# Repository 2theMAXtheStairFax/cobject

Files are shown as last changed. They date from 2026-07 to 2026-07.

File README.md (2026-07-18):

# Sky Cob — Weather Balloon Payload

Sky Cob is UWOSLAB's recoverable, high-altitude weather balloon payload. It's built around a SpeedyBee F405 Wing flight controller running INAV, packaged inside a 3D-printed shell, and monitored over an ELRS RC link. This repo holds everything needed to reproduce the payload build: the flight controller configuration, the radio (transmitter) model, and the 3D-printable enclosure.

> [!CAUTION]
> Please read this description in full before starting!

## Repository contents

| File | What it is |
|---|---|
| `INAV_9.0.1_cli_SKY_COB_20260701_003845.txt` | INAV 9.0.1 CLI dump for the flight controller (target `SPEEDYBEEF405WING`). Paste/load this into the INAV Configurator CLI tab to reproduce the full flight controller setup. |
| `Sky Cob.yml` | EdgeTX radio model ("Sky Cob") for the transmitter — ELRS module setup plus telemetry screens (RSSI, GPS, altitude, battery, attitude, flight mode). |
| `cobshell.stl` | Main payload shell in upright position. |
| `cobby20x40.stl` | Receiver and VTX Mounting plate |
| `cobbyspeedy-top.stl` | Top mounting plate sized for the SpeedyBee F405 Wing FC. |
| `cobby19mm_cam_stand.stl` | Main Chassis for components. |
| `fix model.stl` | Current Shell model in printing orientation for 250x250 bed. |

## Related projects

- [sky-cob-configurator](https://github.com/2theMAXtheStairFax/sky-cob-configurator) — a simplified, balloon-only fork of INAV Configurator. Strips out everything irrelevant to a servo-only, non-autonomous balloon payload (motor mixer, RTH, failsafe, etc.) and adds a one-click "Apply Balloon Defaults & Reboot" button to set up a fresh flight controller. Verified against real Sky Cob hardware. See [docs/weather-balloon-configurator.md](docs/weather-balloon-configurator.md) for the design and status.

## Hardware you'll need

- SpeedyBee F405 Wing flight controller (INAV target `SPEEDYBEEF405WING`)
- GPS module (uBlox; config uses SBAS/WAAS + Galileo + BeiDou + GLONASS) Preferred: HGLRC M100 Pro or Foxeer M10
- ExpressLRS receiver, Radiomaster DBR4 preferred.
- High power VTX. Read your VTXs manual for Band, Channel, Power, and Unlocking procedures.
- microSD card, for blackbox logging. Maximum 4GB usable, any extra space will not be utilized.
- 3D printer capable of printing the shell/mount parts above
- An EdgeTX compatible transmitter with an ELRS module, for `Sky Cob.yml`. Preferred Module for ground station telemetry tracking: Radiomaster Nomad on a Radiomaster Boxer

## Setup

### 1. Print the payload shell and assemble

Print `cobby20x40.stl`, `cobbyspeedy-top.stl`, `cobby19mm_cam_stand.stl`, and `fix model.stl`. Test-fit the FC mount (`cobbyspeedy-top.stl`) against your actual SpeedyBee F405 Wing board before committing to a full print run, since mounting hole tolerances are easy to get slightly wrong between printers/materials.

> [!WARNING]
> Models and files are still WIP. Please check for any recent updates before starting.

1. Place the flight controller in its bay. Make sure the orientation is correct when inserting. Place the FC cover on top and screw down with M2.5 bolts. Self tapping and machine screws will both work, as long as the FC is firmly mounted without wiggling.
2. Mount the GPS on the top platform with double sided VHB tape or glue, direction does not matter as we will not be using its built in compass (if your GPS unit has one).
3. Place the RX and VTX on the 20x20mm holes in the X shaped mounting plate. Bolt through the receiver and into the VTX using M2 bolts. Place the subassembly on the rear 40x40mm standoffs and bolt it down with the RX facing inwards and the VTX outwards.
4. Use double sided VHB tape, glue, or battery straps to mount your 5G GPS tracker to the rear side of the chassis, between the 2 large holes towards the bottom. Do the same with your 12V/3S battery on the other side.
5. Mount your analog camera to the 19mm wide bracket at the bottom. It should be pointing staight down.

### 2. Flash and configure the flight controller (INAV 9.0.1)

1. Install the [INAV Configurator](https://github.com/iNavFlight/inav-configurator) Git release 9.0.2.
2. Flash the `SPEEDYBEEF405WING` target to the board. use INAV 9.0.1 when flashing.
> [!IMPORTANT]
> - Install ImpulseRC Driver Fixer if you have not already, this will let you install the DFU BOOTLOADER Drivers.
> - If target is not found automatically, check if a new COM port has been listed in the top right dropdown and select it before switching to the Firmware Flasher tab.
> - If flashing 9.0.1 from default configurator settings is unsuccessful, unplug the FC and hold down the boot button on the USB board while plugging it in. Select the new COM port and enable "No reboot sequence" in the flasher.
3. Connect to the board and open the **CLI** tab.
4. Load `INAV_9.0.1_cli_SKY_COB_20260701_003845.txt` (drag-and-drop or the "Load" button), or paste its contents directly into the CLI.
5. Let the batch run to completion — it ends with `save`, which reboots the FC with the new configuration.
6. Recalibrate the accelerometer (Calibration tab) — the dump includes calibration offsets (`acczero_*`, `accgain_*`, `gyro_zero_*`) taken from the original unit, and these won't be accurate for a different board. Recalibrate using standard board orientation, not the orientation it will be in once mounted.
7. In the **Modes** tab, review the `Arm` switch assignment. it should be set to Aux 5 with mid to high sections being enabled. OSD controls are on AUX6, 7, and 8.
8. Insert your microSD card into the slot on the FC, you will have to remove the top WIFI board of the FC to reach it. In the blackbox logging tab, check to see if the SD Card is detected and format it. (remember, max 4GB usable. Any extra space will not be used.)

Other defaults worth knowing about:
- `osd_units = IMPERIAL`, `tz_offset = -240` (EDT/Ohio Time)
- `name = SKY COB`, `pilot_name = UWOSLAB`
- Blackbox is enabled and logs `NAV_POS`, `NAV_PID`, `MAG`, `ACC`, `ATTI`, `RC_DATA`, `RC_COMMAND`, `MOTORS`, `SERVOS` — insert a microSD card before flight.

### 3. Set up the transmitter

1. Use an EdgeTX radio (the model file targets EdgeTX 2.11.x — use EdgeTX Buddy if your radio is not up to date).
2. Copy `Sky Cob.yml` to the radio's `/MODELS` folder (Either by removing the SD card in the radio or plugging in via USB and selecting **USB MASS STORAGE** when prompted on the radio),
3. select the **Sky Cob** model on the radio.
4. Confirm the external module is set to CRSF and internal is off.
5. if no telemetry is listed, check the telemetry page for sensors. If no sensors are listed, select "discover sensors" and "stop discovery" once all sensors are listed and no more show up after 30 seconds.
6. Your telemetry pages should now list payload telemetry.

> [!NOTE]
> Technically a radio is not required for setup, you can use the module plugged into the ground station and a separate battery for power. However, it is recommended to use one as backup and for future implementation (gimbal?)

### 4. Pre-flight checklist

- [ ] Fully charged 3S/12V battery is inserted and plugged in. 
- [ ] microSD card inserted and formatted for blackbox logging.
- [ ] GPS has a lock (multi-constellation: GPS + SBAS/WAAS + Galileo + BeiDou + GLONASS) 5-8 sats minimum before launch. takes 30 seconds to 3 minutes from cold start.
- [ ] VTX band/channel (R)ace Band, Channel 8, 5917Mhz, full transmit power.
- [ ] Radio charged, powered on, and bound/connected to the payload.
- [ ] Laptop/Ground Station charged, setup, and plugged in the USB port on the ELRS Module.

### 5. Channel Mapping
> [!NOTE]
> The radio file is setup as preferred by 2theMAX. You may change switch layouts on your radio by going to the mixer tab and setting that channel to the desired switch.

| Function | Channel | Switch | Position |
|---|---|---|---|
| ARMING | 5 | SD | Mid-High (keep high) |
| OSD Off | 6 | SC | High |
| OSD 2nd Page | 6 | SC | Mid |
| OSD 1st Page | 6 | SC | Low |
| Beeper | 7 | SB | Mid-High |

> [!WARNING]
> Position refers to microsecond range (1000us - 2000us), NOT physical switch position. You can double check in the outputs tab and reverse the channel for desired behavior. If you do reverse a channel, check the model settings failsafe menu for default switch positions or else your radio will yap at you about switch postitions when switching models or powering on.

## Questions

For build-specific questions (frame fit, receiver binding, launch procedures), reach out to 2theMAX the Stair Fax directly.

## Prior Knowledge

This project requires basic setup knowledge of radio systems, flight software, control software, as well as basic soldering and digital electronics. It is not recommended to use AI/LLMs for setup due to their out of date training and the rapid advancements of the technologies utilized in this project.

Please consult the following resources for aid when setting up this project.

* [expresslrs.org](https://www.expresslrs.org/)

* [Joshua Bardwell — YouTube channel](https://www.youtube.com/channel/UCX3eufnI7A2I7IkKHZn8KSQ/videos) (search for the latest ELRS setup tutorial)

* [Painless360 — YouTube channel](https://www.youtube.com/user/Painless360/videos) (search for the latest INAV setup tutorial)

* [EdgeTX wiki/site](https://edgetx.org/)

* [OscarLiang.com](https://oscarliang.com/)

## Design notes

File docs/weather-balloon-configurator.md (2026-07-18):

# Weather-Balloon Configurator — Design Doc

> **Status: functional, in use.** The fork lives at [2theMAXtheStairFax/sky-cob-configurator](https://github.com/2theMAXtheStairFax/sky-cob-configurator) (forked from `iNavFlight/inav-configurator`, `upstream` remote wired for future syncs). Verified end-to-end against both Demo Mode (SITL virtual FC) and the real Sky Cob SpeedyBee F405 Wing board over serial.

## Goal

A simplified, Electron-based configurator for weather balloon payloads built on stock INAV firmware (no firmware fork). It exposes only the settings a balloon build needs and provides a one-click way to push the balloon-specific baseline config to a fresh or reset flight controller.

## Non-goals

- No custom firmware build/compile step, no new INAV target, no reflashing a modified binary. The FC keeps running stock INAV; only its stored configuration changes.
- No motor mixer, no autonomous navigation (RTH, waypoints, geozones, safehomes), no multirotor/heli-specific tabs.
- Not a general-purpose INAV Configurator replacement — anything outside the balloon use case is deliberately left out of scope, not just hidden. (This is also why this fork is not a candidate for a PR back into upstream INAV Configurator — see "Upstream contribution" below.)

## What was actually built

Rather than the CLI-diff-generator architecture originally sketched below (kept for history), the simpler and more robust approach turned out to be: strip the UI down tab-by-tab, and reuse the Configurator's own existing CLI-mode plumbing for the one place a "push config" action was actually needed (initial balloon setup).

1. **Tab removal.** Deleted Mission Control, SITL (the manual build/config tab), PID Tuning, Advanced Tuning, Adjustments, LED Strip, Programming, and JavaScript Programming — nav entries, `gui.js` `allowedTabs`, `configurator_main.js` wiring, and the tabs' own HTML/JS/CSS (~14k lines). Also removed the Failsafe tab (a balloon should keep going and stay armed on RC loss, matching `failsafe_procedure = NONE`), the Configuration tab's Power Limits box, and all optical-flow support (sensor dropdown, calibration UI, header status icon).
2. **Servo-only Mixer/Outputs.** Motor-specific sections (Platform Configuration, Mixer Presets, Mixer Wizard, Motor Mixer table, ESC protocol, motor test sliders, reversible-motor fields) are hidden via a `.skycob-hide { display: none !important; }` CSS class rather than deleted, since `Mixer`/`Outputs` share a single MSP load/save chain with the servo-relevant fields we keep. Plain inline `display:none` doesn't survive — `Settings.saveInputs()` calls `parent.show()` on any element with a valid `data-setting`, silently un-hiding it; `!important` does survive that.
3. **Demo Mode.** A lightweight virtual-FC connection (`js/sitl.js` + the `sitl-demo` port option, reusing the bundled SITL binary) for testing the app without real hardware — distinct from the full SITL tab, which stays removed.
4. **No new-FC wizard popup.** Removed `js/defaults_dialog.js` and its wizard step HTML — it walks through multirotor/plane craft-type presets that don't apply here, and it blocked the config view on first connect.
5. **Flat sidebar.** The upstream fork's collapsible accordion nav-groups broke down once most groups were down to 1–2 items (collapsing to a ~1px sliver); replaced with a flat `<li>` list.
6. **Balloon Setup tab** (`tabs/balloon_setup.js`, `js/balloonDefaults.js`) — the actual answer to "push the necessary balloon-only settings to a new FC." A single "Apply Balloon Defaults & Reboot" button runs `defaults noreboot` then applies the curated Sky Cob CLI settings (GPS constellations, blackbox config, AUX/arm switch mapping, OSD units/timezone, VTX band/channel, and the safety settings — `failsafe_procedure=NONE`, `nav_rth_allow_landing=NEVER`, `nav_rth_climb_first=OFF`, `safehome_usage_mode=OFF`). Deliberately excludes acc/gyro calibration (per-board, use the Calibration tab). Implemented by reusing `js/backup_restore.js`'s `BackupRestore` module — already built upstream for backup/restore-around-flashing — to enter CLI mode and send each line with per-line error detection; only saves to EEPROM if every command succeeds.

Verified twice: against Demo Mode (no risk), then against the real connected FC — applied all 98 settings with zero errors, saved, rebooted, re-enumerated normally, and a post-reboot `diff all` confirmed every setting (including the four safety settings) landed correctly.

## Known remaining dead code (left in place deliberately)

`js/transpiler/` (the logic-conditions compiler, now fully orphaned but still has its own test suite) and the `js/fc.js`-wired state models for removed features (geozone, safehome, waypoint, motorMixRule, logicCondition) — those stay because `fc.js` is the shared FC/MSP state object other retained tabs depend on.

One pre-existing, unrelated bug surfaced during verification: `js/appUpdater.js` throws because `window.electronAPI.appGetVersion(...)` isn't a Promise — not caused by anything in this fork's changes, not yet fixed.

## Verification approach

No dedicated test hardware, so tabs that only initialize once connected were verified by driving the running Electron app directly over its Chrome DevTools Protocol port (a small Node script talking to `ws://localhost:9222/devtools/page/...`), checking `element.offsetParent === null` for true rendered visibility (not just an element's own CSS) and capturing console exceptions.

## Distribution

Separate repo from this one on purpose — `sky-cob-configurator` needs its own git history to stay mergeable with `upstream` (iNavFlight/inav-configurator), and is a full Electron app versioned independently of this repo's hardware/build docs. A GitHub Release with a pre-built Windows package is the intended path for non-developers to get a working copy without installing Node.js.

## Upstream contribution

Not planned as a PR into `iNavFlight/inav-configurator` as-is — this fork deletes major functionality (Programming, Mission Control, PID Tuning, LED Strip, etc.) that other users need, so a diff like this would be rejected outright. If contributing back to help other balloon builders is wanted later, the right shape is a separate, additive-only effort against a fresh copy of upstream master: a "Weather Balloon" craft-type preset in the existing Setup Wizard (the one this fork removed) that applies balloon-sensible defaults and optionally hides irrelevant tabs via a toggle, with nothing removed for existing multirotor/plane/rover users.

## Open questions / risks

- **Upstream drift**: forking Configurator UI means periodically re-syncing with upstream INAV Configurator as MSP/CLI protocol or target list changes across INAV releases. Needs an explicit policy (e.g., track one INAV major version at a time).
- **Distribution/signing**: Electron app packaging/signing for Windows/Mac, same burden upstream Configurator already carries — no new problem introduced, just inherited.
- **License**: GPLv3 inheritance from inav-configurator requires this fork's source to also be published under GPLv3.

<details>
<summary>Original CLI-diff-generator sketch (superseded, kept for history)</summary>

The original plan was a "Balloon Profile" JSON document as the single source of truth, with a Save flow that would `diff all`, compute a delta against the profile, and emit a fresh `batch start … save` CLI script enforcing a strip-list on every save — regardless of what was in the UI. In practice this wasn't needed: reusing the existing per-tab MSP save chains (for day-to-day editing) plus a dedicated one-shot "apply the baseline" action (for initial setup, via the Balloon Setup tab) covered the real use cases with far less new code, and no protocol-level diffing was necessary since the curated CLI batch itself is idempotent — applying it twice produces the same result.

</details>

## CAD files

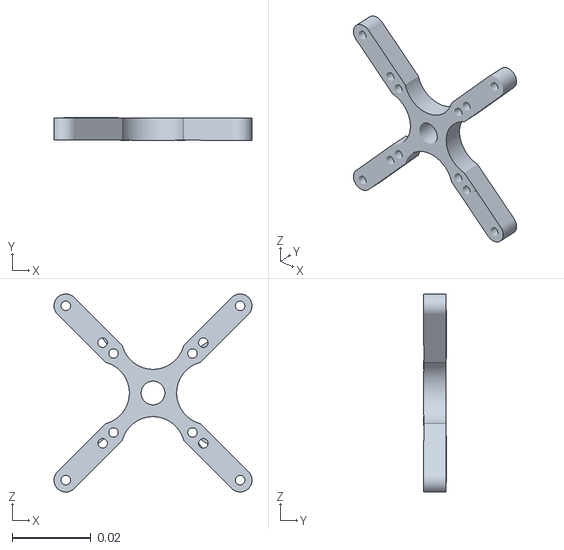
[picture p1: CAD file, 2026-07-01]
cobby20x40.stl
0.0501 x 0.00574 x 0.0501

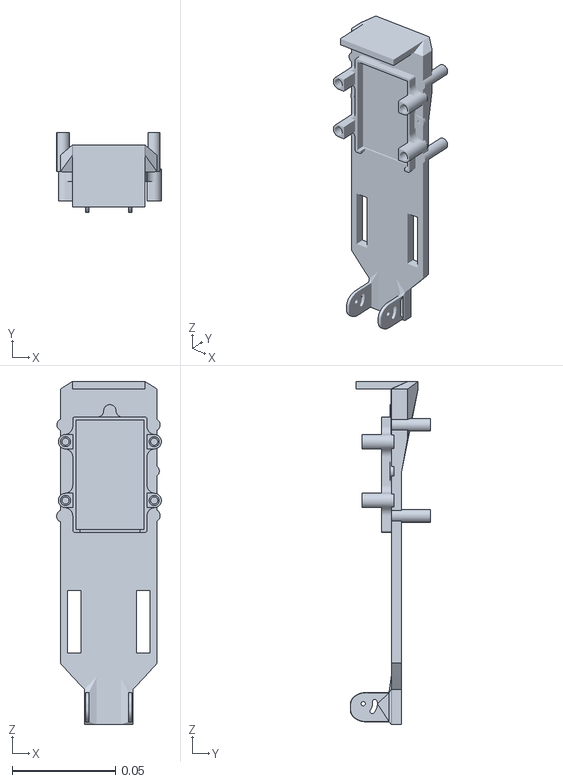
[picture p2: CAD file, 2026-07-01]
cobby19mm_cam_stand.stl
0.0509 x 0.039 x 0.166

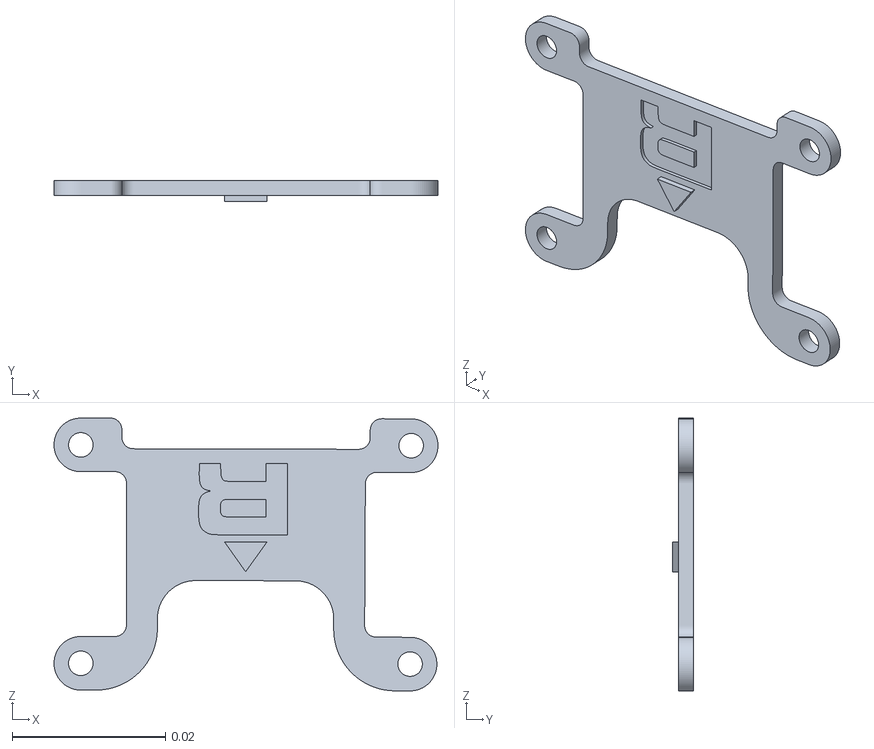
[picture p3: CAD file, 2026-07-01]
cobbyspeedy-top.stl
0.0501 x 0.0028 x 0.0356

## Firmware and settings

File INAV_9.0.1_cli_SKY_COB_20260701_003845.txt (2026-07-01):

diff all

# version
# INAV/SPEEDYBEEF405WING 9.0.1 Feb 13 2026 / 06:49:52 (d44f2cf6) 
# GCC-13.2.1 20231009

# start the command batch
batch start

# reset configuration to default settings
defaults noreboot

# resources

# Timer overrides

# Outputs [servo]

# safehome

# Fixed Wing Approach

# geozone

# geozone vertices

# features
feature GPS

# beeper

# blackbox
blackbox -NAV_ACC
blackbox NAV_POS
blackbox NAV_PID
blackbox MAG
blackbox ACC
blackbox ATTI
blackbox RC_DATA
blackbox RC_COMMAND
blackbox MOTORS
blackbox -GYRO_RAW
blackbox -PEAKS_R
blackbox -PEAKS_P
blackbox -PEAKS_Y
blackbox SERVOS

# Receiver: Channel map
map TAER

# Ports

# LEDs

# LED color

# LED mode_color

# Modes [aux]
aux 0 0 0 1300 2100
aux 1 19 1 1300 2100
aux 2 42 2 1300 1700
aux 3 43 3 1700 2100
aux 4 13 4 1300 2100

# Adjustments [adjrange]

# Receiver rxrange

# temp_sensor

# Mission Control Waypoints [wp]
#wp 0 invalid

# OSD [osd_layout]
osd_layout 0 0 23 0 H
osd_layout 0 1 10 0 V
osd_layout 0 7 13 12 H
osd_layout 0 8 1 12 V
osd_layout 0 9 1 2 H
osd_layout 0 11 1 10 H
osd_layout 0 12 1 9 H
osd_layout 0 14 25 1 V
osd_layout 0 22 28 2 H
osd_layout 0 26 2 2 V
osd_layout 0 28 23 12 V
osd_layout 0 30 1 11 H
osd_layout 0 96 1 1 V
osd_layout 0 97 17 0 V
osd_layout 1 1 1 0 V
osd_layout 1 11 2 10 V
osd_layout 1 12 2 11 V
osd_layout 1 13 23 5 V
osd_layout 1 14 17 2 V
osd_layout 1 20 17 4 V
osd_layout 1 21 17 3 V
osd_layout 1 22 26 2 V
osd_layout 1 23 22 6 V
osd_layout 1 28 23 11 V
osd_layout 1 29 20 10 V
osd_layout 1 30 1 12 H
osd_layout 1 31 23 8 V
osd_layout 1 40 22 7 V
osd_layout 1 97 17 0 V
osd_layout 1 109 2 2 V
osd_layout 1 110 2 3 V
osd_layout 1 112 2 5 V
osd_layout 1 159 2 4 V
osd_layout 1 160 2 6 V
osd_layout 1 161 2 7 V
osd_layout 1 162 2 8 V

# Programming: logic

# Programming: global variables

# Programming: PID controllers

# OSD: custom elements

# master
set gyro_zero_y = -11
set gyro_zero_z = 8
set ins_gravity_cmss =  982.513
set acc_hardware = ICM42605
set acczero_x = -2
set acczero_y = -11
set acczero_z = 36
set accgain_x = 4097
set accgain_y = 4100
set accgain_z = 4100
set align_mag = CW270FLIP
set mag_hardware = FAKE
set baro_hardware = SPL06
set blackbox_rate_denom = 2
set motor_pwm_protocol = STANDARD
set failsafe_procedure = NONE
set failsafe_min_distance_procedure = NONE
set align_board_pitch = 900
set small_angle = 180
set applied_defaults = 1
set gps_sbas_mode = WAAS
set gps_ublox_use_galileo = ON
set gps_ublox_use_beidou = ON
set gps_ublox_use_glonass = ON
set inav_w_z_baro_p =  0.350
set inav_w_z_baro_v =  0.350
set inav_w_z_gps_p =  0.350
set inav_w_z_gps_v =  0.350
set nav_overrides_motor_stop = OFF_ALWAYS
set nav_rth_climb_first = OFF
set nav_rth_allow_landing = NEVER
set safehome_usage_mode = OFF
set nav_mc_wp_slowdown = OFF
set osd_video_system = NTSC
set osd_units = IMPERIAL
set osd_time_alarm = 600
set osd_alt_alarm = 10000
set osd_dist_alarm = 50000
set osd_rssi_dbm_alarm = -100
set osd_switch_indicators_align_left = OFF
set name = SKY COB
set pilot_name = UWOSLAB
set tz_offset = -240
set tz_automatic_dst = USA
set vtx_band = 5
set vtx_channel = 8

# control_profile
control_profile 1


# control_profile
control_profile 2


# control_profile
control_profile 3


# mixer_profile
mixer_profile 1


# Mixer: motor mixer

# Mixer: servo mixer

# mixer_profile
mixer_profile 2


# Mixer: motor mixer

# Mixer: servo mixer

# battery_profile
battery_profile 1


# battery_profile
battery_profile 2

set bat_cells = 3

# battery_profile
battery_profile 3


# restore original profile selection
control_profile 2
mixer_profile 1
battery_profile 2

# save configuration
save

# get nav_extra_arming_safety 
nav_extra_arming_safety = ALLOW_BYPASS
Allowed values: ON, ALLOW_BYPASS


# 

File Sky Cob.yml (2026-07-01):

semver: 2.11.5
header:
  name: Sky Cob
  bitmap: SU27.PNG
  labels: Favorites
  modelId:
    1:
      val: 0
noGlobalFunctions: 0
thrTrim: 0
trimInc: 0
displayTrims: 0
ignoreSensorIds: 0
showInstanceIds: 0
disableThrottleWarning: 1
enableCustomThrottleWarning: 1
customThrottleWarningPosition: -100
beepANACenter: 0
extendedLimits: 1
extendedTrims: 0
throttleReversed: 0
checklistInteractive: 0
flightModeData:
  0:
    name: ""
    fadeIn: 0
    fadeOut: 0
    gvars:
      4:
        val: 256
      5:
        val: 260
      6:
        val: 260
      7:
        val: 260
      8:
        val: 260
  1:
    trim:
      0:
        value: 260
        mode: 0
      1:
        value: 260
        mode: 0
      2:
        value: 260
        mode: 0
      3:
        value: 260
        mode: 0
    swtch: SB0
    name: ""
    fadeIn: 0
    fadeOut: 0
    gvars:
      0:
        val: 0
      1:
        val: 0
      2:
        val: 0
      3:
        val: 0
      4:
        val: 256
      5:
        val: 260
      6:
        val: 260
      7:
        val: 260
      8:
        val: 260
  2:
    trim:
      0:
        value: 260
        mode: 0
      1:
        value: 260
        mode: 0
      2:
        value: 260
        mode: 0
      3:
        value: 260
        mode: 0
    swtch: SB0
    name: ""
    fadeIn: 0
    fadeOut: 0
    gvars:
      0:
        val: 0
      1:
        val: 0
      2:
        val: 0
      3:
        val: 0
      4:
        val: 256
      5:
        val: 260
      6:
        val: 260
      7:
        val: 260
      8:
        val: 260
  3:
    trim:
      0:
        value: 260
        mode: 0
      1:
        value: 260
        mode: 0
      2:
        value: 260
        mode: 0
      3:
        value: 260
        mode: 0
    swtch: SB0
    name: ""
    fadeIn: 0
    fadeOut: 0
    gvars:
      0:
        val: 0
      1:
        val: 0
      2:
        val: 0
      3:
        val: 0
      4:
        val: 256
      5:
        val: 260
      6:
        val: 260
      7:
        val: 260
      8:
        val: 260
  4:
    trim:
      0:
        value: 260
        mode: 0
      1:
        value: 260
        mode: 0
      2:
        value: 260
        mode: 0
      3:
        value: 260
        mode: 0
    swtch: SB0
    name: ""
    fadeIn: 0
    fadeOut: 0
    gvars:
      0:
        val: 0
      1:
        val: 0
      2:
        val: 0
      3:
        val: 0
      4:
        val: 256
      5:
        val: 260
      6:
        val: 260
      7:
        val: 260
      8:
        val: 260
  5:
    trim:
      0:
        value: 260
        mode: 0
      1:
        value: 260
        mode: 0
      2:
        value: 260
        mode: 0
      3:
        value: 260
        mode: 0
    swtch: SB0
    name: ""
    fadeIn: 0
    fadeOut: 0
    gvars:
      0:
        val: 0
      1:
        val: 0
      2:
        val: 0
      3:
        val: 0
      4:
        val: 256
      5:
        val: 260
      6:
        val: 260
      7:
        val: 260
      8:
        val: 260
  6:
    trim:
      0:
        value: 260
        mode: 0
      1:
        value: 260
        mode: 0
      2:
        value: 260
        mode: 0
      3:
        value: 260
        mode: 0
    swtch: SB0
    name: ""
    fadeIn: 0
    fadeOut: 0
    gvars:
      0:
        val: 0
      1:
        val: 0
      2:
        val: 0
      3:
        val: 0
      4:
        val: 256
      5:
        val: 260
      6:
        val: 260
      7:
        val: 260
      8:
        val: 260
  7:
    trim:
      0:
        value: 260
        mode: 0
      1:
        value: 260
        mode: 0
      2:
        value: 260
        mode: 0
      3:
        value: 260
        mode: 0
    swtch: SB0
    name: ""
    fadeIn: 0
    fadeOut: 0
    gvars:
      0:
        val: 0
      1:
        val: 0
      2:
        val: 0
      3:
        val: 0
      4:
        val: 256
      5:
        val: 260
      6:
        val: 260
      7:
        val: 260
      8:
        val: 260
  8:
    trim:
      0:
        value: 260
        mode: 0
      1:
        value: 260
        mode: 0
      2:
        value: 260
        mode: 0
      3:
        value: 260
        mode: 0
    swtch: SB0
    name: ""
    fadeIn: 0
    fadeOut: 0
    gvars:
      0:
        val: 0
      1:
        val: 0
      2:
        val: 0
      3:
        val: 0
      4:
        val: 0
      5:
        val: 0
      6:
        val: 0
      7:
        val: 0
      8:
        val: 0
mixData:
  - destCh: 0
    srcRaw: I0
    weight: 100
    swtch: NONE
    curve:
      type: 0
      value: 0
    delayPrec: 0
    delayUp: 0
    delayDown: 0
    speedPrec: 0
    speedUp: 0
    speedDown: 0
    carryTrim: 0
    mltpx: ADD
    mixWarn: 0
    flightModes: 000000000
    offset: 0
    name: ""
  - destCh: 1
    srcRaw: I1
    weight: 100
    swtch: NONE
    curve:
      type: 0
      value: 0
    delayPrec: 0
    delayUp: 0
    delayDown: 0
    speedPrec: 0
    speedUp: 0
    speedDown: 0
    carryTrim: 0
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

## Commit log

2026-07-18 Add CLAUDE.md, workspace file, and configurator design/status doc; link the new companion repo
    - CLAUDE.md: repo-onboarding notes for this hardware/build-docs repo.
    - cobject.code-workspace: VS Code multi-root workspace including the
    sky-cob-configurator sibling repo.
    - docs/weather-balloon-configurator.md: design doc for the companion
    Electron configurator, updated to reflect what was actually built
    and verified (tab removal, servo-only Mixer/Outputs, Demo Mode, the
    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
2026-10-14 Add generated cob/door/chassis STEP files, their CadQuery generator, and a project doc PDF
